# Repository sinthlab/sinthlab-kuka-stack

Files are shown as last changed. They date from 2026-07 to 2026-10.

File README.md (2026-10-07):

# Sinthlab KUKA Stack

A ROS 2 (Jazzy) control stack for running **compliant "apple‑pluck" experiments** on a KUKA
LBR iiwa7. It is built as an *overlay* on top of the [`lbr_fri_ros2_stack`][^1], adding the
high‑level experiment orchestration, motion actions, and the KUKA Sunrise (FRI) applications
needed to drive the arm.

All experiments run in FRI **position** mode, with the **cabinet** (`LbrImpedanceControlServer`)
providing the Cartesian spring at 1000 Hz. Apple-pluck / perturb stream **joint** setpoints via
`LBRJointPositionCommandController`; restricted-plane / maze stream a fixture-constrained **Cartesian
equilibrium** via `kuka_clik_controller`. Python state machines sequence each trial
(move → cue → monitor displacement → recoil → repeat).

The repo also carries the physical end of the rig: the parametric
[end‑effector design](end_effector_design/README.md) and the
[end‑effector board firmware](end_effector_metro_code/README.md) — a NeoPixel cue ring triggered
over a hardwired media‑flange line, whose **appearance is configured on the board over its own
Wi‑Fi**, see [§6.7](#67-end-effector-board--the-visual-cue).

**To run an experiment, start with the
[experiment control dashboard](#quick-start-the-experiment-dashboard)**, a local web page for
picking an experiment, editing its parameters, Start / Pause / Stop, changing cues between trials,
and following the status and log. Every experiment can also be run from a terminal
([§5](#5-running-experiments-on-hardware)).

Why FRI **position** mode rather than torque mode (ROS-side impedance), and when torque mode would be
worth reconsidering, is in the [appendix](#appendix--why-fri-position-mode-not-torque-mode).

## Table of Contents
- [Quick start: the experiment dashboard](#quick-start-the-experiment-dashboard)
- [1. Hardware Setup (KUKA Arm)](#1-hardware-setup-kuka-arm)
- [2. Windows Laptop Setup](#2-windows-laptop-setup)
- [3. Building the Stack](#3-building-the-stack)
- [4. Simulation & Visualization (no hardware)](#4-simulation--visualization-no-hardware)
- [5. Running Experiments on Hardware](#5-running-experiments-on-hardware)
  - [Pre-training — Free Move, Move Vertical, Move Horizontal](#pre-training--free-move-move-vertical-move-horizontal)
- [6. Software Architecture](#6-software-architecture)
- [7. Data Collected](#7-data-collected)
- [8. Troubleshooting](#8-troubleshooting)
- [9. Development & Contributing](#9-development--contributing)
- [Acknowledgement](#acknowledgement)
- [Appendix — why FRI position mode, not torque mode](#appendix--why-fri-position-mode-not-torque-mode)

---

## Quick start: the experiment dashboard

The quickest way to run an experiment is the **experiment control dashboard**, a local web page on
the ROS computer. From it you:

- pick one of the four experiments, or a pre-training task;
- check or change its parameters;
- Start, Pause, Stop and Restart it;
- change cues and other live settings between trials;
- follow the trial, its events and the full log.

Every experiment can still be run from a terminal instead: see
[§5](#5-running-experiments-on-hardware) and [Without the dashboard](#without-the-dashboard). How the
dashboard is built is in [`experiment_ctrl_gui/README.md`](experiment_ctrl_gui/README.md).

> ⚠️ **Stop is not an emergency stop.** It sends Ctrl-C to the launch. **The SmartPad E-stop is the
> E-stop.** On the first run of any experiment, work in **T1** with a hand on it.

### Start the dashboard
On the ROS computer wired to the arm, with the workspace built ([§3](#3-building-the-stack)):

```bash
~/lbr-stack/src/sinthlab-kuka-stack/experiment_ctrl_gui/run_gui.sh     # then open http://localhost:8080
```

Under WSL2 a Windows browser works, because Windows forwards `localhost` to WSL. `run_gui.sh`
sources ROS 2 and the workspace first. The page needs nothing extra installed and loads nothing
from the internet.

**Try it without the robot first.** This runs a simulated experiment with the same controls;
nothing is launched and nothing connects to the arm:

```bash
python3 ~/lbr-stack/src/sinthlab-kuka-stack/experiment_ctrl_gui/server.py --demo
```

| Option | Effect |
|---|---|
| `--port 8081` | serve on another port |
| `--robot-name lbr` | the arm's ROS namespace (default `lbr`) |
| `--demo` | simulated robot: nothing is launched |
| `--host 0.0.0.0` | serve beyond this computer. **Anyone who can reach the port can start the robot.** Prefer an SSH tunnel: `ssh -L 8080:localhost:8080 <ros-box>` |

### The page
- **Left column:** the experiment list (tabs **Experiments** and **Pre-training**), the **Run** controls, and a **Before you start** checklist
  with the SmartPad selections for the chosen experiment.
- **Middle column:** the **status**, then the **parameters**. Status shows the trial number, the
  current phase, the trial's steps, and a list of every event.
- **Log:** on the right on a wide screen, below on a narrow one.
- **Top bar pills:** the ROS connection, the robot (FRI session state and `lbr_state` rate), and the
  run state.

### Running an experiment
1. **Pick the experiment:** Apple Pluck, Apple Pluck Perturb, Restricted Plane or Maze; or, under
   **Pre-training**, Free Move, Move Vertical or Move Horizontal ([§5](#pre-training--free-move-move-vertical-move-horizontal)).
2. **Prepare the SmartPad.** Start `LbrImpedanceControlServer` and make the selections listed under
   *Before you start*: FRI send period, remote IP, stiffness profile, damping, elbow stiffness. **If the arm is nearly
   straight** (mechanical zero, or close to it), the app then asks to move it to the ready pose
   `[0, 10, 0, −80, 0, 90, 0]` — answer **Move to ready pose** and hold the enabling switch while it
   moves. The app then waits about 60 s for ROS.
3. **Check the parameters** ([below](#live-per-run-and-fixed-parameters)). Edited rows get an
   `edited` badge, and ↺ puts one back to the YAML value. Hover over any parameter for its full
   help.
4. **▶ Start.** This runs `ros2 launch sinthlab_bringup <experiment>.launch.py`, plus your edited
   parameters if you changed any. The status card then follows each trial, e.g.
   `start → at start → quiet → go cue → armed → threshold → recover → end`.
5. **Change live settings** on the **Live** tab at any time. A change applies **from the next
   trial**; the trial in progress is never changed. Until then the row shows a purple
   `next trial → …` badge, and the log records when the change was accepted and when it was applied.
6. **⏸ Pause after trial** lets the current trial finish. The arm recovers to the start and **holds
   there, still under control and compliant**. **▶ Resume** starts the next trial, with any live
   changes made meanwhile. Pressing the button again before the trial ends cancels the pause.
   **Free Move** has no trial end, so there the button (labelled **End session & pause**) ends the
   session at once: the arm holds, waits to be let go, returns to the start and holds.
7. **Stop:**
   - **■ Stop after trial:** finishes this trial, returns to the start, then stops cleanly, so every
     trial on disk is complete. **Use this one.** In **Free Move** (labelled **End session & stop**) it
     ends the session at once, waits for the hand to let go, returns to the start, then stops.
   - **■ Stop now:** Ctrl-C at once. The trial in progress is saved with `"partial": true`, and the
     arm stays where it is — it is not returned to the start.
   - **↻ Restart:** Stop now, then Start again with the current edits.
8. **Validate recording** checks this run's data folder
   (`analysis/validate_recording.py --folder …`) and prints the result in the log. To plot the
   run afterwards, see [Working with the data](#working-with-the-data).

**The log** is the launch's own output from every node, colour-coded by level. Filter it by level or
text, or turn off *Follow* to scroll back. It is also saved to `experiment_ctrl_gui/logs/`.

**An experiment started in a terminal** is picked up automatically. Live changes and pause work
from the page; stop it with Ctrl-C in its own terminal.

### Live, Per-run and Fixed parameters

| Tab | When it can change | What is in it |
|---|---|---|
| **Live** | Any time, **including while running**; applies from the next trial | cue switches, colours, tones and timing; NSP sync; move speeds; the pull threshold and hold; the perturbation; the start pose (apple pluck / perturb); the maze timeout ([full list](#live-parameters)) |
| **Per-run** | Before **Start**, then **locked for the run** | everything else in the experiment YAML: the start pose in restricted plane / maze, rails, checkpoints and goal, move tolerances, safety limits, the fixture profile, the displacement axis, frames, debug logging |
| **Fixed** | Not from the dashboard: at the SmartPad or in the file named | what every experiment shares: SmartPad (FRI) selections, launch arguments, `iiwa7_hardware_controllers.yaml`, the CLIK redundancy posture |

- **Your edits never change the package YAML.** They go into a copy for that run, and every
  recorded trial's sidecar keeps the full parameter set it ran with, live changes included.
- **Poses** are 7 joint angles in degrees. They are checked against the iiwa7 joint limits, and a
  nearly straight (singular) arm is refused — by the dashboard and again by the orchestrator.
  - **Start and recover are edited together**, because the next trial starts where the last one
    recovered to. A live change sends both in one call; one on its own is refused.
  - **Apple Pluck / Perturb:** the pose is live. The next trial moves to it and recovers to it.
  - **Restricted Plane and Maze:** the CLIK redundancy posture follows an edited start pose
    automatically.
  - **Maze:** a new start moves the whole maze with it. Run `check_maze.py` on the edited copy
    before trusting it.
- **Amber ⚠ notes** flag parameters other things depend on; **blue 🔗 notes** name what else an
  edit changes. Rails and checkpoints must keep their number of entries; adding a rail is a YAML
  edit.
- **Values are checked** for type, range and allowed choices before they are sent, and again inside
  the orchestrator. A refused change says why.

### Live parameters
**Every experiment:**

| Parameter | Meaning |
|---|---|
| `quiet_window_sec` | pause at the start pose before the go cue [s] (default 2.0) |
| `audio_cue.enabled` | master switch for every beep; off, the trial runs the same but silent |
| `audio_cue_*.frequency_hz`, `audio_cue_*.duration_ms` | each tone (37–32767 Hz, 10–10000 ms) |
| `visual_cue.enabled` | master switch for the NeoPixel ring |
| `visual_cue.remote_test_trigger` | fire the ring over its Wi-Fi (demos) or the X76 wire |
| `visual_cue.colours.<site>` | `[r, g, b, w]` per cue site (Wi-Fi trigger only) |
| `nsp_sync.enabled` | send event codes to the Blackrock NSP. **The DIO is not wired yet**: when on, it warns once and sends nothing ([§7](#sync-to-the-blackrock-nsp)) |
| `move_to_start.move_to_pos_v_max` / `_a_max` / `_j_max`, and the same for `move_to_start_recover` | move speed limits: peak joint speed 5–90 deg/s, acceleration 0.5–20 rad/s², jerk 1–150 rad/s³. The next move uses them. |

**Plus, per experiment** (`…displacement` = `apple_pluck_impedance_control_displacement`):

| Experiment | Extra live parameters |
|---|---|
| Apple Pluck | `…displacement.cartesian_displacement_threshold_m`, `…displacement.force_release_shutdown_delay_sec`, **the start / recover pose** (`move_to_start.target_joint_position`, `move_to_start_recover.target_joint_position`, set together) |
| Apple Pluck Perturb | everything Apple Pluck has, plus `…displacement.baseline_settle_sec`, `perturb_start.polar_r_m` (capped per plane), `perturb_start.polar_theta_deg`, `perturb_start.polar_plane`, `perturb_start.start_delay_sec`, and the perturbation's speed limits `perturb_start.move_to_pos_v_max` / `_a_max` / `_j_max` |
| Restricted Plane | `…displacement.cartesian_displacement_threshold_m`, `…displacement.force_release_shutdown_delay_sec` |
| Maze | `timeout_sec`, `virtual_fixtures.rail_lead_sec` (how easy moving along a rail feels: + lighter, − heavier, −0.15 to +0.05 s) |
| Free Move | `session_sec` (0 = until Pause / Stop after trial); the ring `ring_cue.quarters`, `ring_cue.colours.*`; the feel `free_move.damping_ns_per_m` (3–200, lower = lighter), `free_move.deadband_n` (0–15), `free_move.max_speed_mps` (≤ 0.5), `free_move.accel_limit_mps2`, `free_move.force_filter_tau_sec`, `free_move.tare_sec` |
| Move Vertical / Move Horizontal | `timeout_sec`, `virtual_fixtures.rail_lead_sec`, the task `travel_task.threshold_m` / `direction` / `require_return` / `return_tolerance_m`, the ring `ring_cue.quarters`, `ring_cue.colours.*` |

These are deliberately **not** live:
- `cartesian_axis`: it changes what the threshold means, so it is a different experiment, not a
  different trial.
- **Safety limits:** a limit must not be loosened mid-session.
- **Move tolerances** (`joint_move_tolerance`, `cartesian_move_tolerance`): they decide when a move
  counts as arrived.
- **The start pose in Restricted Plane and Maze:** those experiments hand the arm to the CLIK, whose
  redundancy posture must equal the start pose and is read once, when the controller starts; and the
  maze's geometry hangs off the start. Edit it per-run (the posture then follows automatically).
- **Maze rails, checkpoints and goal:** verified offline by `check_maze.py`.
- **The pre-training rails:** checked by IK for reach; edit them per-run.

### Parameter help
Each parameter shows a one-line description. **Hover over its name**, or tab to it, for the full
help:
- the type, YAML default, and allowed range or choices;
- whether it is live;
- the **notes from the YAML**: the reasoning, measurements and knobs;
- any caution or linked parameters.

Group headings and Fixed rows have the same help. To send someone straight to one parameter's help:
`http://localhost:8080/?exp=perturb&hover=perturb_start.polar_theta_deg`.

All of it is read from the YAML files themselves, so the page and the files cannot disagree. To
document a new parameter, see [§9](#9-development--contributing).

### Without the dashboard
The same controls from a terminal (namespace `lbr`, apple pluck shown). The orchestrator nodes are
`apple_pluck_orchestrator`, `perturb_orchestrator`, `restricted_plane_orchestrator` and
`maze_orchestrator`; for pre-training, `free_move_orchestrator` and `rail_training_orchestrator`
(Move Vertical and Move Horizontal).

```bash
ros2 launch sinthlab_bringup iiwa7_apple_pluck_impedance_control.launch.py                 # start; Ctrl-C stops
ros2 launch sinthlab_bringup iiwa7_apple_pluck_impedance_control.launch.py params_file:=/path/edited.yaml

ros2 topic echo /lbr/experiment_status                                                     # where the run is
ros2 param set /lbr/apple_pluck_orchestrator visual_cue.enabled false                       # live: next trial
ros2 param set /lbr/apple_pluck_orchestrator move_to_start.move_to_pos_a_max 1.0             # slower approach
ros2 service call /lbr/apple_pluck_orchestrator/pause std_srvs/srv/SetBool "{data: true}"   # pause after trial
ros2 service call /lbr/apple_pluck_orchestrator/pause std_srvs/srv/SetBool "{data: false}"  # resume
```

A `ros2 param set` on anything that is not live is **rejected with the reason**, because the
orchestrator read it once at start-up. The start and recover poses must change together, so set them
in one atomic call, `ros2 service call /lbr/apple_pluck_orchestrator/set_parameters_atomically …`, or
from the dashboard; `ros2 param set` on one of them alone is refused. The maze, restricted-plane and
pre-training launches also accept `clik_nullspace_cfg:=`.

### Files the dashboard writes
| Where | What |
|---|---|
| `experiment_ctrl_gui/runs/<exp>_<time>.yaml` | the edited parameter copy a Start used (only when something was edited), plus `…_clik_nullspace.yaml` when a CLIK start pose was edited |
| `experiment_ctrl_gui/logs/<exp>_<time>.log` | the full launch output of each run |
| `analysis/expt_<run_name>_<time>/` | the trial recordings, written by the orchestrator as always ([§7](#7-data-collected)) |

None of these are committed to git.

### If something is wrong
- **"ROS ✗" in the top bar.** The dashboard was started without ROS sourced, so use `run_gui.sh`.
  Start, Stop and the log still work, but live changes, pause and robot state need ROS.
- **"Robot: no state".** Nothing is publishing `/lbr/lbr_state` yet: the launch has not connected
  to FRI, or the SmartPad app is not running or timed out. Restart the app, then Start.
- **The run pill stays on "Starting…".** The orchestrator has not reported yet. Look in the log for
  its first lines or an exception.
- **A live change is refused.** The message gives the reason: not a live parameter, out of range, or
  wrong type. A per-run parameter needs Stop, edit, Start.
- **Stop takes a while.** The nodes shut down in order. After 20 s the dashboard escalates, and the
  log says so.
- **"Dashboard disconnected".** The dashboard server stopped. Restart it. If it was running an
  experiment, that experiment was stopped cleanly when the server stopped.

---

## 1. Hardware Setup (KUKA Arm)
- Use the "Quick Start guide" to cable up the Arm, Cabinet and the SmartPad.
- For the Safety on the X11 interface in the Cabinet:
  - First create 6 jumper cables with the provided pins.
  - Based on the PIN diagram (pg‑53 of `Spez_KUKA_Sunrise_Cabinet_en.pdf`, section 6.6.2),
    jump pins 1/2, 10/11 (external E‑Stop), 3/4, 12/13 (Operator Safety) and 5/6, 14/15
    (Safety stop 1).

---

## 2. Windows Laptop Setup
> **Why Windows + WSL2?** KUKA's robot software (Sunrise Workbench) requires Windows, while our
> stack requires Ubuntu. We use the Windows laptop to install applications onto the robot, and
> run our stack inside WSL2 (Ubuntu) on the same laptop to control the arm.

### Prerequisites
- Install Ubuntu 24.04 with `wsl --install -d Ubuntu-24.04` (the version matters — do **not**
  install the default).
- Confirm you are on WSL version 2 (`wsl -l -v` shows the version and the installed distro).
- Make sure the robot controller box is on.
- Install `Sunrise Workbench` on the laptop. For our arm version we use
  `SunriseWorkbench-1.17.0.4-setup.exe`, provided by KUKA Support.
- Install the FRI plugin in the Sunrise Workbench project (steps to be elaborated).

### Connection Verification
- Connect your computer to the robot controller at **X66** (default IP `172.31.1.147`) via an
  ethernet cable.
- Put your computer on the same network — set your IP to `172.31.1.148` (or anything else in the
  `/16` subnet).
  - On Windows: Settings → Network & Internet → Ethernet, edit the IPv4 manual setup to IP
    `172.31.1.148` and gateway `255.255.0.0`; leave other options as is and save.
- Ping the robot from PowerShell — `ping 172.31.1.147` — and expect something like:
  ```
  PING 172.31.1.147 (172.31.1.147) 56(84) bytes of data.
  64 bytes from 172.31.1.147: icmp_seq=1 ttl=64 time=0.868 ms
  ```
- Enable Hyper‑V on the laptop.
- Set up networking for WSL2: open WSL settings (in the Start menu) and change the Networking
  mode to **Mirrored**.
  
- In a PowerShell window **with admin privileges**, allow inbound Hyper‑V connections:
  ```powershell
  Set-NetFirewallHyperVVMSetting -Name '{40E0AC32-46A5-438A-A0B2-2B479E8F2E90}' -DefaultInboundAction Allow
  ```

### Install Application to Robot
Follow [these steps](https://lbr-stack.readthedocs.io/en/latest/lbr_fri_ros2_stack/lbr_fri_ros2_stack/doc/hardware_setup.html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)
to install the application to the robot. Our application is
[`sunrise_controller_code/LbrImpedanceControlServer.java`](sunrise_controller_code/LbrImpedanceControlServer.java);
redeploy it from Sunrise Workbench whenever that file changes.

### Tool Load Data (payload calibration)
The cabinet must know the end‑effector's mass, or the compliant control modes (Cartesian / joint
impedance) refuse to activate. With an uncalibrated tool the experiment launch aborts with:
```
[lbr_fri_ros2::StateGuard]: External torque not in limits for joint lbr_A2. Measured: 2.4 Nm, limit: 2 Nm
... External torque limits exceeded. Perform load data calibration!
```
You define a **tool** in Sunrise Workbench, then let the controller measure its mass and centre of
mass with the smartPAD's **Load data** view (Sunrise.OS 1.16 SI manual §7.5; ours is 1.17).

1. **Define the tool** in Sunrise Workbench — open the project's `RoboticsAPI.data.xml` and add a
   tool under `objectTemplates`. Keep the TCP at the flange (all‑zero transform) so the FRI control
   point stays aligned with the ROS `lbr_link_ee`, and leave `loadData` at zero (Determine fills it):
   ```xml
   <objectTemplates>
     <toolTemplate class="" defaultMotionFrameRef="/SinthLabIiwa7EE_link_ee" name="SinthLabIiwa7EE">
       <frames>
         <frame name="SinthLabIiwa7EE_link_ee">
           <transformation a="0.0" b="0.0" c="0.0" x="0.0" y="0.0" z="0.0"/>
         </frame>
       </frames>
       <loadData cogA="0.0" cogB="0.0" cogC="0.0" cogX="0.0" cogY="0.0" cogZ="0.0"
                 inertiaX="0.0" inertiaY="0.0" inertiaZ="0.0" mass="0.0"/>
     </toolTemplate>
   </objectTemplates>
   ```
   `defaultMotionFrameRef` must match the frame name exactly. **Synchronize** the project to the controller.
2. **Determine the load** on the smartPAD, in **T1**: at the **Robot** level select the **Load data**
   tile → pick `SinthLabIiwa7EE` → hold the enabling switch → **Determining the load data** →
   **Apply**. Then **synchronize** the project so Sunrise Workbench keeps the values.
   - Only the wrist moves: A7 goes to 0° then to −90°, and A6 swings ±95° (A1–A4 stay put). Tick
     **Restricted motion range for axis 6** (±15° around the start) if the effector could hit the arm.
   - Start from a pose well away from singularities, and make sure nothing on the tool can move: tie
     down cables and any battery pack. Loose parts, or anyone touching the robot, falsify the result.
   - **Below 1 kg KUKA calls the mass measurement unreliable.** Weigh the effector, enter the mass in
     the tool's `loadData`, synchronize, then choose **Use existing mass** so only the centre of mass
     is measured.
3. **Attach the tool in the FRI app** so the cabinet actually compensates it: in
   `sunrise_controller_code/LbrImpedanceControlServer.java`, create the tool
   (`createFromTemplate("SinthLabIiwa7EE")`), `attachTo(lbr_.getFlange())`, and move the **tool**
   instead of the bare flange. Without this the guard still trips even after Determine.

> **Apply** stores the mass / COM on the controller; synchronizing copies them back into the project's
> `RoboticsAPI.data.xml`. Re‑run after any change to the end‑effector — a different apple height or a
> moved battery pack counts. The `gravitation` vector in `RoboticsAPI.data.xml` assumes a standard floor mount;
> set it to match if the arm is mounted otherwise.

---

## 3. Building the Stack
> These steps run inside **WSL2 / Ubuntu 24.04**.

1. Install ROS 2 development tools (see this [guide](https://docs.ros.org/en/jazzy/Installation/Ubuntu-Install-Debs.html) for details):
   ```bash
   sudo apt update && sudo apt install locales
   sudo locale-gen en_US en_US.UTF-8
   sudo update-locale LC_ALL=en_US.UTF-8 LANG=en_US.UTF-8
   export LANG=en_US.UTF-8
   sudo apt install software-properties-common
   sudo add-apt-repository universe
   sudo apt update && sudo apt install curl -y
   export ROS_APT_SOURCE_VERSION=$(curl -s https://api.github.com/repos/ros-infrastructure/ros-apt-source/releases/latest | grep -F "tag_name" | awk -F'"' '{print $4}')
   curl -L -o /tmp/ros2-apt-source.deb "https://github.com/ros-infrastructure/ros-apt-source/releases/download/${ROS_APT_SOURCE_VERSION}/ros2-apt-source_${ROS_APT_SOURCE_VERSION}.$(. /etc/os-release && echo ${UBUNTU_CODENAME:-${VERSION_CODENAME}})_all.deb"
   sudo dpkg -i /tmp/ros2-apt-source.deb
   sudo apt update && sudo apt install ros-dev-tools
   sudo apt update
   sudo apt upgrade
   sudo apt install ros-jazzy-desktop
   sudo apt install python3-pip
   ```
2. Create a workspace, clone, and install dependencies:
   ```bash
   source /opt/ros/jazzy/setup.bash
   mkdir -p lbr-stack/src && cd lbr-stack
   vcs import src --input https://raw.githubusercontent.com/sinthlab/sinthlab-kuka-stack/main/sinthlab_lbr_stack.repos
   rosdep install --from-paths src -i -r -y
   ```
3. **(Hardware only, one-time)** Raise the FRI external-torque limit. `lbr_fri_ros2` checks the
   *external joint torque at activation of compliant control modes*. On a
   floor-mounted iiwa7 this trips (~2.4 Nm on A2 vs. the 2 Nm default) at the extended apple-pluck
   start posture **even with no payload** — it's a gravity-model / mastering margin amplified by A2's
   moment, not a real load. Edit the upstream config
   `src/lbr_fri_ros2_stack/lbr_description/ros2_control/lbr_system_config.yaml` and raise the limit
   (keep the check enabled):
   ```yaml
   state_guard:
     external_torque_safety_check: true
     external_torque_limit: 4.0   # upstream default is 2.0
   ```
   Skip this for mock/sim. The proper long-term fix is calibrating the mounted tool's load data (see
   §2 “Tool Load Data”) so the residual stays under the default — raising the limit is the stopgap
   while the flange is load-free.
4. Install the required Python packages (only needed once per WSL session install):
   ```bash
   pip install pyoptas ruckig --break-system-packages
   ```
5. Build:
   ```bash
   colcon build --symlink-install
   ```

---

## 4. Simulation & Visualization (no hardware)

The experiments themselves need the real arm: the cabinet provides the impedance spring and the
force estimate, which no simulation here reproduces. To try the trial flow and the dashboard without
it, run the dashboard in demo mode ([Quick start](#quick-start-the-experiment-dashboard)). To look at
the arm itself:

**Mock arm in RViz** (upstream `lbr_bringup`)
```bash
# Terminal 1 — the mock arm
source install/setup.bash
ros2 launch lbr_bringup mock.launch.py model:=iiwa7
```
```bash
# Terminal 2 — visualize
source install/setup.bash
ros2 launch lbr_bringup rviz.launch.py \
  rviz_cfg_pkg:=lbr_bringup \
  rviz_cfg:=config/mock.rviz
```

**Physics simulation in Gazebo** (upstream `lbr_bringup`)
```bash
source install/setup.bash
ros2 launch lbr_bringup gazebo.launch.py model:=iiwa7
```

**MoveIt with apple (mock or gazebo)**
```bash
source install/setup.bash

# Mock + MoveIt + RViz
ros2 launch sinthlab_bringup iiwa7_moveit_apple.launch.py mode:=mock rviz:=true

# Gazebo + MoveIt + RViz
ros2 launch sinthlab_bringup iiwa7_moveit_apple.launch.py mode:=gazebo rviz:=true
```

---

## 5. Running Experiments on Hardware
> Python dependencies (`pyoptas`, `ruckig`) must be installed once per WSL session install (see
> [Building the Stack](#3-building-the-stack)).
>
> ⚠️ **Safety first.** On the first run of any scenario, operate in **T1** (reduced speed) with a
> hand on the E‑stop. The arm is actively controlled the moment a SmartPad application is running.
>
> **Starting from mechanical zero.** A straight arm is singular, and impedance control cannot move it
> reliably. If `LbrImpedanceControlServer` starts with the arm nearly straight, it asks to move it to the
> ready pose `[0, 10, 0, −80, 0, 90, 0]` in position control first; answer **Move to ready pose**. From
> there every experiment's start is reachable. An arm already bent (e.g. at a start pose) is not moved.

### Running from the dashboard
The [dashboard](#quick-start-the-experiment-dashboard) runs exactly the launches below, with the
SmartPad checklist, parameters, status and log on one page. The steps below are the terminal way, and
what the dashboard does for you. The launches accept `params_file:=/path/to.yaml` to run an edited
parameter copy; the maze, restricted-plane and pre-training launches also accept `clik_nullspace_cfg:=`.

### Scenario quick reference
| # | Scenario | Launch file | SmartPad app (FRI) | ROS controller |
|---|---|---|---|---|
| 1 | Apple Pluck | `iiwa7_apple_pluck_impedance_control.launch.py` | `LbrImpedanceControlServer` | `LBRJointPositionCommandController` |
| 2 | Restricted on Plane  | `iiwa7_move_restricted_plane.launch.py` | `LbrImpedanceControlServer` | `kuka_clik_controller` |
| 3 | Apple Pluck Perturb  | `iiwa7_apple_pluck_impedance_perturb.launch.py` | `LbrImpedanceControlServer` | `LBRJointPositionCommandController` |
| 4 | Maze | `iiwa7_maze.launch.py` | `LbrImpedanceControlServer` | `kuka_clik_controller` |
| P | Pre-training (Free Move, Move Vertical, Move Horizontal) | `iiwa7_pretrain_<task>.launch.py` | `LbrImpedanceControlServer` | `kuka_clik_controller` |

**One control paradigm.** Every scenario uses FRI **POSITION** command mode with the **cabinet**
(`LbrImpedanceControlServer`) running the Cartesian impedance spring at 1000 Hz. They differ only in
what ROS streams into it:

- **Apple Pluck / Perturb (1 & 3)** — **joint** setpoints via `LBRJointPositionCommandController`
  (straight to the FRI position command, no IK).
- **Restricted-plane / Maze (2 & 4)** — a fixture-constrained **Cartesian equilibrium** via
  `kuka_clik_controller` (Cartesian target → IK → joint positions).

> **The two things that decide how a fixture feels:**
>
> 1. **Soft-inside comes from tracking, not from low stiffness.** Inside the allowed region the
>    fixture's projection returns the *measured* pose, so the spring error — and hence the force — is
>    ~zero **whatever K is**. High K only bites at the walls and on locked axes. What breaks this is
>    **tracking lag**: if the commanded equilibrium cannot keep up with the operator's hand it falls
>    behind *cumulatively* and `K × error` is felt as resistance in every direction. That is governed
>    by `kuka_clik_controller.max_linear_velocity` (**1.0 m/s**, well above hand-guiding speed) and
>    the fixture's `max_target_step_m` (**0.05 m**).
> 2. **Use an anisotropic stiffness profile.** `LbrImpedanceControlServer` takes a full per-axis
>    `{X,Y,Z,A,B,C}` diagonal. A *uniform* profile forces one compromise for locked axes, walls and
>    free motion alike, and for the maze no uniform value works (400 = mushy walls, 3000 = heavy
>    everywhere). Lock the constrained axis hard and keep the free axes firm enough for
>    walls; the interior stays free by (1).

### Scenario 1 — Apple Pluck
This scenario streams **joint** setpoints to the `LBRJointPositionCommandController` (joint positions
go straight to the FRI position command — no IK), while the KUKA cabinet runs Cartesian impedance
natively via the `LbrImpedanceControlServer` FRI app. The arm acts as a virtual physical spring and
recoils when pushed off its commanded anchor.

**Start pose — the apple points at the monkey.** The effector is tilted **25° below horizontal** toward
the monkey (+X), so the monkey pulls the apple toward itself and the NeoPixel ring faces it. Flange
≈ (0.40, 0, 0.75) m, apple ≈ (0.56, 0, 0.68) m in `lbr_link_0`, reached with the in-plane posture
`[0, −15.5, 0, −94.3, 0, 36.2, 0]`. It was solved by IK against the iiwa7 URDF, and the arm can be
pulled at least 0.30 m toward the monkey before nearing a joint limit or singularity. A **pluck** is any
**0.1 m** pull from the start, in any direction (`cartesian_axis: norm`), because the pull is toward
the monkey rather than along one base axis. Tilt, roll and height knobs are documented next to the
pose in `config/apple_pluck_impedance.yaml`.

**Steps to run:**
1. On the KUKA SmartPad, start the **`LbrImpedanceControlServer`** application. It opens five
   selection dialogs in sequence — choose:

   | Prompt | Select |
   |--------|--------|
   | FRI send period [ms] | `10` |
   | Remote IP address | `172.31.1.148` (your ROS / WSL2 laptop IP) |
   | Cartesian stiffness (K diagonal) | `Uniform Medium (Apple Pluck)` |
   | Damping ratio (D0) | `0.7 (Standard)` |
   | Null-space (elbow) stiffness | `30 (Standard)` |

   *This app is hard‑wired to Cartesian Impedance control in `POSITION` command mode. The other
   stiffness profiles (`Very Soft Z`, `Soft Z (Apple Pluck)`, `Stiff (firm walls)`, …), damping ratios
   (`0.1`, `0.2`, `0.3`, `1.0`) and elbow stiffnesses (`15`, `5`) are available if you want to change
   the feel.*
   The app then waits (~60 s) for the ROS client to connect.
2. **Launch the experiment** — this connects ROS to the waiting FRI app and starts the trial loop
   (nothing happens until you run this):
   ```bash
   ros2 launch sinthlab_bringup iiwa7_apple_pluck_impedance_control.launch.py
   ```
3. The arm moves to the start. At the beep (and a **green** ring, if the visual cue is on) pull the
   apple toward you; **0.1 m** in any direction counts. A second beep and a **red** ring confirm it,
   the arm holds for a moment, then returns to the start.

### Scenario 2 — Move Restricted on a Plane
This scenario applies mathematical **virtual fixtures** (planes, boxes, cylinders, sine rails): the
arm moves freely *within* an allowed region and is pushed back *outside* it. `kuka_clik_controller`
streams a **fixture-constrained equilibrium** pose (the measured pose projected onto the allowed
manifold) and the cabinet's Cartesian impedance turns that into the free-motion + wall feel at 1000 Hz.
Along a free axis the equilibrium tracks the arm, so the spring error — and the force — is ~zero; off
the manifold it stays put, so the spring pulls the arm back.

**Steps to run:**
1. On the KUKA SmartPad, start the **`LbrImpedanceControlServer`** application. It opens five dialogs:

   | Prompt | Select |
   |--------|--------|
   | FRI send period [ms] | `10` |
   | Remote IP address | `172.31.1.148` (your ROS / WSL2 laptop IP) |
   | Cartesian stiffness (K diagonal) | **`Rail guide (uniform 1000)`** |
   | Damping ratio (D0) | `0.7 (Standard)` |
   | Null-space (elbow) stiffness | `30 (Standard)` |

   The app then waits (~60 s) for the ROS client to connect.
2. **Launch the experiment** — this connects ROS to the waiting FRI app and starts it:
   ```bash
   ros2 launch sinthlab_bringup iiwa7_move_restricted_plane.launch.py
   ```
3. The arm rises to the workspace; pull it and feel it held onto the sine rail — free along the pull
   axis, walled in the other two.

> **Tune the feel with the SmartPad stiffness profile.** `Rail guide (uniform 1000)` pins X and holds
> the arm to the rail in Y, while Z (the pull axis) stays free because the equilibrium tracks it. If
> the pull feels heavy *while moving* rather than at the rail, that is tracking lag, not stiffness —
> raise `kuka_clik_controller.max_linear_velocity`.
>
> **Tip:** Set `virtual_fixture_profile` (`sine_wave`, `flat_table`, …) in
> `virtual_fixtures_params.yaml` — this defines *where* the fixture is. For the sine rail, size the
> **wavelength against the pull stroke** — below ~1 period over the stroke it reads as a straight lean.

#### How this relates to Apple Pluck — same cabinet compliance, different ROS controller
Both run the **same cabinet Cartesian impedance at 1000 Hz**; they differ in what ROS streams:

| | Apple Pluck (1 & 3) | Restricted Plane / Maze (2 & 4) |
|---|---|---|
| SmartPad app | `LbrImpedanceControlServer` | `LbrImpedanceControlServer` |
| Compliance | **cabinet** Cartesian impedance, 1000 Hz | **cabinet** Cartesian impedance, 1000 Hz |
| ROS controller | `LBRJointPositionCommandController` | `kuka_clik_controller` |
| ROS streams | **joint** positions (the start config) | a **Cartesian** pose projected onto the fixture manifold |
| Stiffness profile | uniform (omnidirectional spring) | **anisotropic** (lock one axis, firm walls on the others) |
| Feel | omnidirectional spring toward one pose | free within the fixture; firm wall outside it |

So the cabinet — not Python — supplies the give: the arm yields to a sudden jerk at 1 kHz, and the
"walls" are **soft impedance walls** (the arm is gently pulled back onto the manifold), which is the
safer behaviour for an animal subject. The software (`MoveRestrictedOnAPlaneAction`) just keeps the
spring's equilibrium inside the allowed region.

### Scenario 3 — Apple Pluck Perturb
This scenario builds upon the Apple Pluck physics (cabinet‑side Cartesian impedance via
`LbrImpedanceControlServer`, with `LBRJointPositionCommandController` streaming the joint setpoints) but
introduces a sudden, programmatic Cartesian spatial shift right before the user acts, to study the
response to mechanical perturbation.

It uses the **same start pose** as Apple Pluck (apple pointing at the monkey). The pluck threshold is
**0.1 m** in any direction (the same as Apple Pluck), measured from where the arm settles after the
perturbation.

**Tuning the perturbation** — `perturb_start` in `config/apple_pluck_impedance_perturb.yaml`:

| Knob | Effect |
|---|---|
| `polar_r_m` | How far the apple is displaced [m]. Default `0.05`. **Capped per plane:** frontal 0.15, horizontal 0.175, sagittal 0.10 m, so every direction stays ≥ 10° from every joint limit. Larger r also tilts the flange more (up to ~22° at the frontal cap). |
| `polar_plane` | `frontal` (default) — the plane **facing the monkey**, so the apple never moves toward or away from it. `horizontal` / `sagittal` — θ = 0 points **at** the monkey. |
| `polar_theta_deg` | Direction in that plane. For `frontal`: `0` = +Y (sideways), `90` = up, `180` = −Y, `270` = down. |
| `move_to_pos_a_max`, `move_to_pos_j_max` | **How fast.** On a short move the acceleration and jerk limits set the duration. |
| `move_to_pos_v_max` | Per-joint speed cap. It never binds on a 5–10 cm perturbation. |
| `start_delay_sec` | Wait after the start cue before the perturbation begins [s]. Default `1.5`. |

Measured from the start pose at r = 0.05 m (motion of the impedance anchor):

| `a_max` / `j_max` | Duration | Peak apple speed |
|---|---|---|
| 2 / 5 *(default)* | 0.73 s | 0.13 m/s |
| 5 / 20 | 0.46 s | 0.20 m/s |
| 10 / 50 | 0.34 s | 0.28 m/s |
| 20 / 150 | 0.23 s | 0.40 m/s |

The physical apple follows the anchor through the impedance spring, so it lags a very fast perturbation.

**Steps to run:**
1. On the KUKA SmartPad, start the **`LbrImpedanceControlServer`** application with the **same
   selections as Scenario 1**:

   | Prompt | Select |
   |--------|--------|
   | FRI send period [ms] | `10` |
   | Remote IP address | `172.31.1.148` (your ROS / WSL2 laptop IP) |
   | Cartesian stiffness (K diagonal) | `Uniform Medium (Apple Pluck)` |
   | Damping ratio (D0) | `0.7 (Standard)` |
   | Null-space (elbow) stiffness | `30 (Standard)` |

   The app then waits (~60 s) for the ROS client to connect.
2. **Launch the experiment** — this connects ROS to the waiting FRI app and starts it:
   ```bash
   ros2 launch sinthlab_bringup iiwa7_apple_pluck_impedance_perturb.launch.py
   ```
3. The arm acts as the standard pluck, but **1.5 s after the start cue** (`start_delay_sec`) it moves
   the apple **5 cm sideways** in the plane facing the monkey. Pull from where it settles: **0.1 m** in
   any direction counts.

### Scenario 4 — Maze
The operator (or animal) drives the compliant arm along a network of **linear rails** in a **vertical
Y‑Z plane** in front of the robot. It reuses the same fixture engine as Scenario 2
(`MoveRestrictedOnAPlaneAction` with the `maze` profile). Hitting a checkpoint plays a reward cue
(**any order, once each**); reaching the goal — or timing out — stops the fixtures, waits for the
operator to let go, and resets to the start.

**The legs are LINES, not corridors.** Each "corridor" in `maze_params.yaml` is a *degenerate*
rectangle — a horizontal leg has `b_min == b_max`, a vertical leg has `a_min == a_max` — so the fixture
always projects the equilibrium onto the **nearest segment**, exactly like the sine rail. You slide
*along* a rail and can only turn at a junction; there is no free area to wander in.

**Why vertical, and why this start posture.** The tool axis (the EE frame's **Z** axis) points ~+X at
the subject, and the maze locks base‑X so the plane is enforced by the cabinet. The start posture
matters more than it looks: both fixtures **lock orientation**, and translating the EE while holding
orientation is far more expensive in some arm configurations than others. The start posture reaches
its EE pose with the **elbow flipped** relative to the obvious solution, which puts the cost of sideways
motion at ‖q̇‖ ≈ 2.5 instead of ≈ 19.8 (6D condition number 10 instead of 45). In the other posture the
maze is heavy in exactly the directions it is supposed to be free.

**Workspace limits (measured by IK, holding tool orientation).** From the shipped start the arm can
reach **a ∈ [−0.40, +0.40] m** sideways and **b ∈ [−0.35, +0.20] m** up/down — but that envelope is a
**trapezoid**: full width low down, pinched at the top (at b = +0.20 only a ∈ ±0.10).

**Why the maze sits entirely at or below the start.** Climbing is hard on this arm for two independent
reasons, both measured:

| | sideways cost | vertical cost | gravity at the tool |
|---|---|---|---|
| low (b = −0.15) | 2.8 | **3.4** | −5.3 N |
| high (b = +0.15) | 3.4 | **8.6** | −5.4 N |

1. The gravity-compensation residual is a constant **~5.5 N downward**, so climbing fights it and
   descending is assisted.
2. **Vertical conditioning degrades with height** — the cost of vertical motion with orientation held
   is 3.4 low down but **8.6** near the top, 2.5× the sideways cost there.

So the maze's rows are at **b = 0, −0.11 and −0.22**: every vertical leg is in the well-conditioned
lower region and gravity is on the operator's side. The depth stops at −0.22 so the goal row stays at
a comfortable height (z ≈ 0.64 m in the base frame).

**The maze is defined RELATIVE to the start EE** (`corridor_frame: relative`, `relative_to_start: true`),
so its origin is wherever the arm starts: change `move_to_start` and the whole maze — rails, checkpoints,
goal — moves with it. It is anchored on the **settled measured** pose, not the commanded one
(`anchor_settle_sec: 3.0`, `anchor_on_measured: true`): a free axis carries no restoring force, so the
arm sinks a few cm below the commanded start; anchored on the command, the whole maze would sit that
far overhead and the checkpoints would be missed.

#### What you should expect to see

A **2-D maze** of linear rails on a 0.15 m grid — shaded cells are solid, you can only travel the
rails, and only one route reaches the goal. Coordinates are **offsets from the anchored start**
(▶ = 0,0): **a = Y sideways, b = Z up/down**; X (in/out) is locked by the cabinet.

```
   a:      -0.30     -0.15      0.00     +0.15
         ┌────────────────────────────┐
 b  0.00 │░░░░░░░░░░░░░░░░░░▶════════┐│  ▶ START
         │░░░░░░░░░░░░░░░░░░░░░░░░░░░║│
 b -0.11 │┌════════◆═════════════════┘│  ◆ fork (reward cue)
         │║░░░░░░░░║░░░░░░░░░░░░░░░░░░│
 b -0.22 │└════════◆═════════════════★│  ★ GOAL — below the start
         └────────────────────────────┘
            the two ◆ are the only choices; every vertical leg is DESCENDED
            ░ = solid (no rail)     ═ ║ ┌ ┐ └ ┘ = rail you can travel
```

**A checkpoint fires only where a turn decision is actually made** — the **two** junctions offering a
real choice (◆). Every other junction is a corner where the turn is forced, and arriving at one tells
the subject nothing to act on, so it gets no cue. A reward tone therefore means exactly one thing:
**"you are at a fork — choose."**

| fork | the choice |
|---|---|
| (−0.15, −0.11) | drop here for the **short** route, or carry on left and drop at a = −0.30 (**long**) |
| (−0.15, −0.22) | turn right for the goal, or left along the bottom (the long way round) |

The descent at a = −0.15 is a **single rail** from the first fork straight down to the second — nothing
branches off it in between, so its midpoint is not a junction and deliberately gets no cue.

**The choice is which column to descend.** Drop at a = −0.15 for the **short route (0.97 m)**, or carry
on to a = −0.30 and drop there for the **long route (1.27 m)**. Both reach the goal row, so there are
**no dead ends** — a wrong choice costs travel rather than trapping the arm. Every vertical leg is
descended, never climbed.

**The walls hold you.** The fixture latches onto the rail you are travelling and will only hand you
over to a rail that *physically touches* it — a real junction. Push sideways mid-rail and the
equilibrium stays clamped to that rail, so the cabinet spring pulls you back onto it. A hard push can
never make an unrelated rail "nearest" and drag the arm through a wall.

**The gap matters.** On the b=0 row there is deliberately **no rail between a=−0.15 and a=0.00**
(the shaded cells left of ▶). Without it the arm could run straight from START to the goal up-link and
the maze would be trivial — that gap is what forces the long way round.

Every rail is verified reachable by IK while holding the tool orientation (40 samples along the rails,
all reachable, sideways cost median 2.9 / max 3.5).

#### Changing or extending the maze

**The maze is pure configuration — you never edit code to change it.** Everything lives in
`sinthlab_bringup/config/maze_params.yaml`, and the geometry is *relative to the start*, so the whole
maze follows `move_to_start` automatically.

**Rails** are four parallel arrays under the `maze` profile — one entry per segment:

```yaml
#                R1     R2     R3   ...
corridor_a_min: [ 0.00,  0.15, -0.30, ...]   # a = Y sideways
corridor_a_max: [ 0.30,  0.15,  0.30, ...]
corridor_b_min: [ 0.00, -0.15, -0.15, ...]   # b = Z up/down
corridor_b_max: [ 0.00,  0.00, -0.15, ...]
```

A **horizontal** rail has `b_min == b_max`; a **vertical** rail has `a_min == a_max`. If both spans are
non-zero you have made a *box* — an open area the arm can wander inside — not a rail.

**Rules the maze must obey**

| rule | why |
|---|---|
| no key defined twice in the same block | YAML silently keeps the **last** one, so the file says one thing and ROS loads another |
| every rail linear (degenerate in one axis) | otherwise it is an open box, not a corridor |
| all four `corridor_*` arrays the same length | they are read positionally |
| START `(0,0)` lies on a rail | otherwise the arm begins pinned against a wall |
| segments **touch** to form junctions | rails that don't touch are separate; the arm can't cross between them |
| every checkpoint and the goal lies on a rail | a waypoint off the rails can never be triggered |
| `checkpoint_x/y/z/radius` the same length | read positionally, like the rails |
| `maze_safety.max_displacement_m` exceeds the farthest rail point | otherwise the safety stop fires mid-trial |
| fits the reachable envelope | see below |

**Reach.** Holding the tool orientation, the arm covers **a ∈ [−0.40, +0.40]**, **b ∈ [−0.35, +0.20]**,
and that envelope is a **trapezoid** — full width low down, sharply pinched at the top (at b = +0.20
only a ∈ ±0.10). Vertical room is the scarce resource; sideways room is plentiful.

**If you change `move_to_start`**, you must also update `config/clik_nullspace_maze.yaml`
(`nullspace_desired_configuration`) to the same joint array, or the CLIK will hold the right EE pose in
the wrong arm posture. And re-check the *orientation-constrained* cost of the free directions — that is
what decides whether guiding feels light or like treacle, and it is not visible in reach alone.

**Validate before you touch the robot:**

```bash
# reach checks need a generated URDF (once per shell)
xacro $(ros2 pkg prefix lbr_description)/share/lbr_description/urdf/iiwa7/iiwa7.xacro > /tmp/iiwa7.urdf
export IIWA7_URDF=/tmp/iiwa7.urdf

ros2 run sinthlab_bringup check_maze.py
```

It checks every rule above, then IKs points along each rail to confirm the arm can actually reach them
while holding the tool orientation, and reports the sideways-motion cost. Exit code is non-zero on
failure, so it works in CI. Example of a bad maze:

```
  [--] key 'checkpoint_x' is defined TWICE in the same block (second at line 156).
       YAML keeps the LAST one, so the file does not say what ROS loads.
  [--] rails [10] have width in BOTH axes -- they are boxes, not lines.
  [--] rails [10] are NOT connected to the start -- unreachable, the arm can never enter them.
  [--] CP4 is 70 mm off every rail -- it can never be triggered.
  [--] maze reaches 0.99 m but maze_safety.max_displacement_m is 0.20 -- the safety stop
       would fire mid-trial. Raise it above 0.99.
FAILED (5 problem(s))
```

The duplicate-key check runs **first**. A YAML file with the same key twice parses cleanly and the
later value silently wins, so every other check would pass while the maze loads different values than
the file appears to specify.

Structural checks run without the URDF; the kinematic ones are skipped with a note if `optas` or
`IIWA7_URDF` is unavailable.

**Making it harder.** Add rails (junctions, dead ends, loops), not width. Length is cheap along `a`,
expensive along `b`. A deliberate **gap** between two collinear rails — as between `a = −0.15` and
`a = 0.00` on the b = 0 row — is what forces the long way round; without gaps a grid of rails is just
an open field.

#### Diagnostic ladder

If the maze feels wrong, switch `virtual_fixture_profile` to isolate the cause — these need no code
change, because a rail spanning the whole workspace has no walls and a long thin one *is* a line:

| profile | what it is | what it tests |
|---|---|---|
| `free_plane` | one huge corridor, no reachable wall | the plane lock + stiffness + tracking, with the maze removed |
| `single_line` | one corridor, long in Y, ±2 cm in Z | adds exactly one wall pair |
| `maze` | the real thing | full geometry |

Work up the ladder and stop at the first rung that feels wrong.

**Steps to run:**
1. On the KUKA SmartPad, start the **`LbrImpedanceControlServer`** application:

   | Prompt | Select |
   |--------|--------|
   | FRI send period [ms] | `10` |
   | Remote IP address | `172.31.1.148` (your ROS / WSL2 laptop IP) |
   | Cartesian stiffness (K diagonal) | **`Maze walls + easy guiding (rot 120)`** — `{2500, 1000, 1000, 120, 120, 120}` |
   | Damping ratio (D0) | `0.7 (Standard)` |
   | Null-space (elbow) stiffness | `30 (Standard)` |

   > **Use an anisotropic profile, not a uniform one.** X 2500 locks the radial axis so the cabinet
   > enforces the plane in hardware; Y/Z 1000 holds the arm firmly on the rails. Uniform profiles could
   > never win: 400 made the walls mushy, 3000 made everything heavy.
   >
   > Four maze profiles ship, differing **only in rotational stiffness** — `Maze walls (X lock, Y/Z
   > firm)` 300, `… easy guiding` 120, `… light guiding` 60, `… very light guiding` 30 — so you can A/B
   > the one knob that matters for feel. The maze's constraints are all *translational* (X = the plane, Y/Z =
   > the rails), so orientation stiffness defines nothing about the maze — it only stops the tool
   > twisting. But holding orientation *while translating* is the expensive motion, so dropping it to
   > 120 (or 60, or 30) reduces guiding effort **without** softening the plane or the rails. Trade-off:
   > the tool twists more as rot drops — watch the apple angle.
2. **Launch:**
   ```bash
   ros2 launch sinthlab_bringup iiwa7_maze.launch.py
   ```
3. The arm drives to ▶START. (From a straight arm, the SmartPad app has already moved it to the
   ready pose, from which the maze start is reachable.)
4. The arm settles for 3 s, the fixture anchors on where it **rests**, the go cue plays, and the rails go
   live. Drive to the goal (or let the 60 s timeout expire).

   > **Watching progress.** The fixture logs your maze position at 2 Hz:
   > `maze: a=+0.180 b=+0.002 -> on rail C1`, or `OFF rail (nearest C1, 31 mm away, being pulled back)`.
   > Every run also writes `analysis/robot_trajectory_*.csv` with
   > `time, x, y, z, rel_a, rel_b, corridor, off_rail, rail_dist` — plot `rel_a` vs `rel_b` straight on
   > top of the rail coordinates in `maze_params.yaml`. Set `checkpoint_monitor.debug_log_enabled: true`
   > to also see live distance to each checkpoint and the goal.

> **⚠️ Gravity matters on the free axes.** Along a rail the equilibrium tracks the arm, so the spring
> exerts ~no restoring force in that direction and the tool's weight rests on **gravity compensation**.
> Measured on the bare flange: the arm sinks ~4 cm and then **stops** (bounded, not a runaway). That is
> why the fixture anchors on the settled pose. With the real EE mounted, run tool-load **Determine**
> first — a wrong `loadData` makes the sink larger and biases every vertical leg.
>
> **Safety-stop (backstop, not a substitute).** `SafetyStopMonitor` (`maze_safety` in the params) trips if
> the EE leaves the start pose by > 0.55 m or exceeds 0.7 m/s (for 5 consecutive samples), and **aborts immediately** —
> stops the fixture and drives back to the start posture, no release wait. This exists because the FRI
> velocity guard only *neutralises the command*, it does not halt the trial. It catches a runaway; it does
> not remove the need for correct gravity compensation.
>
> **Tuning the feel.** The goal is effortless movement *along* a rail and a hard wall *across* it.
> Along a rail the spring exerts no force by design (the equilibrium is the arm's own position
> projected onto the rail), so what you feel there comes from lag, damping and the orientation lock.
> The levers, in the order worth trying:
> 1. **`virtual_fixtures.rail_lead_sec`** — the **ease knob**, Live between trials. It aims the
>    equilibrium slightly *ahead* of the arm along the rail it is on, cancelling the tracking lag that
>    reads as drag (the equilibrium reaches the arm a few tens of ms late, and stiffness × speed × lag
>    pulls back). `0` = off; **+0.01 to +0.03** = lighter (at 0.2 m/s, +0.03 is ~6 N of assist);
>    the cap is +0.05, because beyond the real lag the arm starts to pull itself along; **negative** =
>    a deliberate speed-dependent drag, if the task should be harder. It never acts across a rail, so
>    the walls are unchanged, and never leads more than 2 cm.
> 2. **Damping ratio** (SmartPad: 0.1 / 0.2 / 0.3 / 0.7 / 1.0). The cabinet damps the arm's velocity,
>    which is felt as drag along the rail that grows with speed. Lower is lighter; check the walls and
>    the return to start do not ring.
> 3. **Rotational stiffness** (SmartPad maze profile: rot 300 / 120 / 60 / 30): the biggest lever on
>    how heavy guiding feels even when moving slowly, and it costs no fixture fidelity — only more tool
>    twist.
> 4. **Null-space (elbow) stiffness** (SmartPad: 30 / 15 / 5 Nm/rad): how firmly the elbow is held.
>    Moving the flange moves the elbow too, so this is felt as a steady resistance; lower is lighter,
>    but watch the elbow does not swing.
> 5. **Y/Z stiffness**: how firmly you are held on a rail. Raise if the rails feel mushy.
>
> **What is left when all of these are at their lightest** is the arm's own inertia and drive
> friction (about 23 kg of links to move), and the walls catching the part of your push that is not
> exactly along the rail. Separate the two with the ladder: profile **"Diagnostic: nearly free
> (uniform 50, rot 10)"** + `virtual_fixture_profile: free_plane` shows the floor — how light the arm
> can feel at all (diagnostic only; walls and plane lock are meaningless at that stiffness). Then the
> maze profile + `free_plane` adds the plane lock, `single_line` adds one wall pair, and `maze` adds
> the rails. Wherever it gets clearly heavier is the part to work on.
>
> Damping 0.1 / 0.2 apply to the Cartesian spring only; the elbow's damping stays at 0.3, Sunrise's
> minimum for it.
>
> To tell them apart, move along one rail at a steady speed and watch
> `ros2 topic echo /lbr/force_torque_broadcaster/wrench --field wrench.force` (it reads 0 below 2 N).
> Drag that grows with speed is lag or damping; a push-back that is there even when you move slowly
> is the orientation lock or gravity.
>
> If a *free* direction feels heavy no matter what, suspect the **start posture** rather than any of
> these — see the note on orientation-constrained translation above.

> **Moving the maze = changing `move_to_start`.** Because everything is start-relative, the joint start
> pose is the one knob that positions the maze. Everything moves with it automatically — but you still have
> to respect **reach**: holding the start orientation the arm covers **a ∈ [−0.40, +0.40], b ∈ [−0.35,
> +0.20]**, and that envelope is a trapezoid (pinched at the top). Every rail point in the shipped maze
> is verified reachable. If you pick a very different start, re-check the footprint **and** re-check the
> orientation-constrained cost of the free directions — a bad posture reintroduces the treacle feel.
>
> **Two syncs to keep (both are pre-set):**
> - `config/clik_nullspace_maze.yaml` `nullspace_desired_configuration` **must equal**
>   `move_to_start.target_joint_position`. The CLIK matches only the EE *pose* and resolves the arm's
>   redundant 7th DOF toward that posture; a mismatch holds the right pose in the wrong arm shape.
> - `checkpoint_monitor.relative_to_start` and the fixture's `corridor_frame` must **both** be relative (or
>   both absolute), or the rewards land in the wrong place relative to the walls.
>
> **Editing the shape:** rails live in `maze_params.yaml` as `corridor_a_min/a_max/b_min/b_max`
> (with `restricted_axis: x`, `a = Y` sideways and `b = Z` up/down, as **offsets from start**). Keep them
> degenerate — a horizontal leg has `b_min == b_max`, a vertical leg has `a_min == a_max` — or you get a
> box with free area inside it again. Segments must **touch** to form a junction; START (0,0) must lie on
> one; the checkpoint/goal **X**-offset is 0 (on the locked plane), and Y/Z carry the position.

### Pre-training — Free Move, Move Vertical, Move Horizontal
Three short tasks that get a subject used to the arm before the real experiments. In the dashboard
they are under the **Pre-training** tab. All three:

- start at the **maze start** (tool along +X toward the subject), so they share one posture with the
  maze;
- run on the CLIK, like the maze;
- end like the maze: a cue, then the arm holds and waits for the hand to let go, then it returns to
  the start.
- record the same per-trial CSV and sidecar, into `analysis/expt_iiwa7_pretrain_<task>_<time>/`.

| Task | Launch file | SmartPad stiffness | The subject… | Success |
|---|---|---|---|---|
| **Free Move** | `iiwa7_pretrain_free_move.launch.py` | **Rail guide (uniform 1000)** | moves the arm anywhere; it stays where it is let go | no goal — one session, until you end it (Pause / Stop after trial) |
| **Move Vertical** | `iiwa7_pretrain_move_vertical.launch.py` | **Maze walls + easy guiding (rot 120)** | slides it up or down one vertical rail to the threshold (0.10 m), then back | back at the start |
| **Move Horizontal** | `iiwa7_pretrain_move_horizontal.launch.py` | **Maze walls + easy guiding (rot 120)** | slides it left or right along one horizontal rail, then back | back at the start |

Use **damping 0.7** and **elbow 30** for all three. Move Vertical and Move Horizontal share one
orchestrator (`rail_training_orchestrator.py`); their YAML picks the rail. Free Move has its own
(`free_move_orchestrator.py`).

#### Free Move — admittance, no goal, no boundary
The arm goes wherever it is pushed and stays wherever it is let go. There is no goal, no reward and
no wall. It runs as one free-movement **session** until you end it with **Pause** or **■ Stop after
trial** on the dashboard: an end tone plays, the arm holds where it is, waits to be let go, and returns
to the start. There it holds (Pause; **▶ Resume** starts a new session) or the launch stops (Stop after
trial). **■ Stop now** does not return it: the arm stays where it is. For timed sessions instead, set
`session_sec` (live; 0, the default, means no limit).

ROS owns the cabinet spring's **equilibrium** and moves it at a speed proportional to the hand's force
(`speed = force / free_move.damping_ns_per_m`). The cabinet spring then pulls the arm after it
([`admittance_move.py`](sinthlab_bringup/sinthlab_bringup/actions/admittance_move.py)). The CLIK still
does the IK; ROS only moves the target point.

- **The feel is set in the YAML, not on the SmartPad, and all of it is live.**
  - `damping_ns_per_m`: the only resistance — lower is lighter. At 10, 3 N of push moves the arm
    about 0.3 m/s. Very low values may buzz or oscillate; come down gradually.
  - `deadband_n`: a **threshold**, not a subtraction. A force below it moves nothing; above it the
    whole force counts (full from twice the threshold). Raise it if the arm creeps when nobody touches
    it. The force estimator has its own 2 N per-axis dead band on top
    (`estimated_wrench_interface` in `config/iiwa7_hardware_controllers.yaml`).
  - `max_speed_mps`: speed cap, 0.35 m/s by default.
  - `accel_limit_mps2`: **smoothness** — how fast the speed may change (default 1.5 m/s²; 0 = off).
    The force estimate is noisy and flickers across the threshold; without this the speed follows
    every jolt and the motion feels bumpy. Lower is smoother, but slower to start and stop.
  - `force_filter_tau_sec`: low-pass on the force estimate (larger = smoother, but laggier, and lag
    can make low damping oscillate).
- **Where the force comes from** (`force_source`, per-run). By default (`joint_torques`) Free Move
  computes the hand's force itself from the arm's **external joint torques** through the Jacobian
  (`F = pinv(J)ᵀ τ_ext`, lightly damped: `jacobian_damping` 0.02). It does **not** use lbr's estimated
  wrench topic, for two reasons that made diagonal motion bumpy:
  - that estimator has a **per-axis** 2 N dead band, so a diagonal push, split across axes, switches
    on and off axis by axis and its direction snaps between them;
  - its Jacobian inverse is damped at 0.2, which here reads only **47–85 %** of the real force and
    bends its direction by up to **17°**, differently in different directions.

  In an offline test of a 6 N diagonal push, the estimator path barely moved (0.007 m/s, about 26°
  off the push); the joint-torque path moved at full speed within about 2° of it. `force_source:
  estimator` switches back. The estimator topic itself is unchanged, so the release check still uses
  it. Because the force is no longer under-read, the same damping feels **lighter** than with the
  estimator.
- **Why "Rail guide (uniform 1000)".** The spring is what makes the arm follow the moving
  equilibrium and hold where it stops, so it must be firm. At 1000 N/m the arm trails by a few mm. A
  soft profile makes it sag and lag, so it is no longer admittance. Rotation 300 holds the tool
  orientation.
- **The equilibrium is integrated from force, never copied from the arm.** An equilibrium set to
  the measured pose gives zero spring force, and the arm sinks under the gravity residual. That is
  the collapse the threshold give-in once caused. Upstream `lbr_ros2_control/AdmittanceController`
  integrates from the measured joints and assumes a stiff, position-controlled arm, so it is not
  used here.
- **What keeps it safe — none of these limits where the arm may go:**
  - **A leash** (`leash_m`, 3 cm): the equilibrium is never more than this ahead of the arm, so a
    bad force reading can never pull harder than 30 N.
  - **A tare:** the force at rest, about 5 N from the gravity residual, is measured each session
    before the go cue and subtracted.
  - **The runaway monitor** (`free_move_safety`), **speed only** (`max_displacement_m: 0` = no distance
    limit): it aborts to the start if the arm moves faster than 0.7 m/s.
- **No boundary means** the arm can be pushed to the edge of its reach, a joint limit or a singular
  pose — where the CLIK stops and the arm simply stops moving — and into anything near it: the table,
  the chair, its own base. Keep the area clear.
- **What is still felt:** the arm's own inertia and joint friction (as in apple pluck), the damping,
  and the threshold before it starts. The estimate of the hand's force also drifts a little with
  posture, so far from the start some directions can feel slightly assisted or held back.

#### Move Vertical / Move Horizontal — one leg of the maze
Each is the maze's rail fixture with **one straight rail** through the start (`virtual_fixtures.vertical_rail`
or `horizontal_rail`, per-run). The task is in `travel_task`, and all of it is live:

- `threshold_m`: how far out turns the ring red.
- `direction`: `both`, `positive` (up / +Y) or `negative`.
- `require_return`: `false` makes the threshold itself the success.
- `return_tolerance_m`: how close to the start counts as back.

**The ring shows the task.** It holds a state per phase (`ring_cue`, live):

| Phase | Ring |
|---|---|
| from the go cue, travelling out | travel quarters **green** |
| threshold reached, come back | travel quarters **red** (plus `audio_cue_threshold`) |
| success | **blue** (plus `audio_cue_reward`) |
| timeout, and between trials | dark |

`ring_cue.quarters` names the quarters that light: Move Vertical uses `[0, 2]` (up and down),
Move Horizontal `[1, 3]` (left and right), and Free Move all four (green while free to move). Which quarter faces up depends on
how the ring sits on the flange. Light quarter 0 alone once and set the lists to match:
```bash
curl "http://192.168.4.1/segments?factor=4&colors=0,255,0,0"     # quarter 0 green; /off to clear
```
The quarter cues use the board's existing `/segments` endpoint, so **the firmware needs no change**.
They need the **Wi-Fi trigger** (`visual_cue.remote_test_trigger: true`), because the X76 wire carries
one bit, not a pattern.

**Reach and gravity** (IK from the maze start, holding the tool orientation):
- **Sideways is easy:** at ±0.25 m every joint is still ≥ 39° from its limit.
- **Down is easy.**
- **Up is the limit.** The arm nears a singular pose above +0.12 m, and +0.20 m is unreachable.
  Hence the vertical rail is ±0.12 m and the horizontal ±0.15 m, both with a 0.10 m threshold.
- **On the vertical rail nothing holds the arm up** except the load data. An untouched arm sinks a
  few cm and stops; the rail anchors after that settle (`anchor_settle_sec`, during the 4 s quiet
  window). **Check that an untouched arm never reaches the threshold** before a session with a
  subject.

The orchestrator warns at start-up if `threshold_m` is at or beyond the rail end.

#### Before the first session with a subject
1. **Free Move, sign check (T1, hand on the E-stop).** Set `free_move.debug_log_enabled: true`.
   Push the tool gently sideways: **the arm must move with the push.** If it moves against it, stop
   at once; the force frame is wrong.
2. **Free Move, creep and feel.** Leave the arm untouched for 10 s; it must not move. Then move it
   around the space the subject will use, and tune `damping_ns_per_m` and `deadband_n` live.
3. **Move Vertical, gravity.** Let go at the start. The arm must stop well short of the threshold.
4. **Ring.** Confirm the travel quarters really are up/down (or left/right) as seen by the subject.

#### A suggested progression
1. **Free Move:** sessions of free handling, damping lowered as the subject gets confident.
2. **Move Horizontal:** first `require_return: false` (reward at the threshold), then `true`.
3. **Move Vertical:** first `direction: negative` (down only, gravity helps), then `both`.
4. **Maze**, along its own diagnostic ladder: `free_plane` → `single_line` → `maze`.

#### Further pre-training tasks worth adding (not implemented yet)
- **Touch and hold.** The arm holds still; the reward comes for holding the apple (force above a
  level for a time). It teaches contact and needs only the force topic.
- **Wait for go.** The reward is withheld if the arm is moved before the go cue. It teaches the quiet
  window every real experiment starts with.
- **One corner.** An L-shaped, two-rail maze profile (one turn), between the single rails and the
  maze. This needs YAML only.
- **Short pull.** Apple Pluck with a 2–3 cm threshold, raised live as the subject learns. No new code.
- **Automatic staircase.** Raise `threshold_m` by itself after N successes in a row. This is a small
  orchestrator addition.

---

## 6. Software Architecture
The stack separates **hard real‑time physical loops** from **high‑level orchestration**, so that
Python state transitions never compromise the 1000 Hz hardware control loops.

### 6.1 System Overview — data flow
Both paths end in a joint **position command** over FRI, and the **cabinet's Cartesian impedance
provides the compliance**. Every start and recover move sends **joint** setpoints via
`LBRJointPositionCommandController`, and so does the whole apple-pluck / perturb trial. For their
fixture phase, restricted-plane / maze switch to `kuka_clik_controller` and send a fixture-constrained
**Cartesian equilibrium**, which it IKs to joints. Robot state flows *back up* to the Python actions
and the recorder, and the operator drives the orchestrator from the dashboard or a terminal.

```mermaid
flowchart TB
    OPS["Operator<br/>dashboard or terminal"]
    ORCH["<b>Layer 3</b> · Orchestrator node (one per experiment)<br/>+ ExperimentControl: status · pause · live params"]
    ACT["<b>Layer 3</b> · Actions<br/>moves · perturbation · freeze · fixture / maze · monitors · cues"]
    REC["<b>Layer 3</b> · TrialRecorder<br/>CSV + JSON sidecar per trial"]
    KIN["<b>Layer 2</b> · Kinematics<br/>optas FK · tf2 poses"]
    JPC["<b>Layer 1</b> · LBRJointPositionCommandController<br/>joint positions → FRI<br/>apple / perturb, every start / recover move"]
    CLIK["<b>Layer 1</b> · kuka_clik_controller<br/>Cartesian equilibrium → IK → joints<br/>fixture phase (switched in by the orchestrator)"]
    EE["End-effector cue ring"]
    APP["<b>Cabinet · 1000 Hz</b> · LbrImpedanceControlServer (FRI app)<br/>per-axis Cartesian impedance · POSITION mode"]
    ARM["iiwa7 arm"]
    BCAST["<b>Layer 1</b> · Broadcasters<br/>lbr_state · joint_state · force_torque"]

    OPS -- "launch · status · live params · pause" --> ORCH
    ORCH --> ACT
    ORCH -- "events" --> REC
    ACT -. "FK / pose" .-> KIN
    ACT -- "LBRJointPositionCommand" --> JPC
    ACT -- "PoseStamped target_frame" --> CLIK
    ACT -- "cue" --> EE
    JPC -- "joint position cmd (FRI)" --> APP
    CLIK -- "joint position cmd (FRI)" --> APP
    APP <--> ARM
    APP -- "FRI state" --> BCAST
    BCAST -- "LBRState · wrench" --> ACT
    BCAST -- "LBRState (cabinet clock)" --> REC

    classDef l3 fill:#e8f0fe,stroke:#4a6fd0,color:#111
    classDef l2 fill:#eef7ee,stroke:#4a9a4a,color:#111
    classDef l1 fill:#fff4e5,stroke:#d08a2a,color:#111
    classDef hw fill:#f3e8fd,stroke:#8a4ad0,color:#111
    class ORCH,ACT,REC l3
    class KIN l2
    class JPC,CLIK,BCAST l1
    class APP,ARM,EE hw
```

Blue: Layer 3, orchestration (Python). Green: Layer 2, kinematics (Python). Orange: Layer 1,
real-time control (C++, ros2_control). Purple: hardware.

The actions, one by one, are in the [§6.2 table](#62-composition--the-launch-brings-up-hardware-the-orchestrator-runs-the-experiment).
The visual cue currently fires over the ring's Wi-Fi (a test trigger); the X76 wire is planned
([§6.7](#67-end-effector-board--the-visual-cue)).

> **Where the "feel" is decided.** The fixture geometry (Python) says *where* the walls are; the
> cabinet's **per-axis stiffness** says *how firm* they are; and the **tracking clamps**
> (`kuka_clik_controller.max_linear_velocity`, `virtual_fixtures.max_target_step_m`) decide whether the
> allowed region feels free. All three must be set together — see the note in section 5.

### 6.2 Composition — the launch brings up hardware, the orchestrator runs the experiment
The codebase keeps a hard line between **hardware bring‑up** and **experiment logic**, and that line
*is* the launch ↔ orchestrator boundary:

```mermaid
flowchart LR
    D["dashboard or terminal"] -- "ros2 launch<br/>[params_file:=…]<br/>[clik_nullspace_cfg:=…]" --> L["iiwa7_*.launch.py<br/>(thin per-experiment wrapper)"]
    L --> B["experiment_base.launch.py<br/>(shared)"]
    B --> HW["iiwa7_hardware.launch.py<br/>FRI client · ros2_control<br/>robot_state_publisher · controller spawners"]
    B --> O["orchestrator node<br/>trial state machine"]
    O --> A["actions<br/>(moves · monitors · cues · controller switch)"]
    O --> C["ExperimentControl<br/>status · pause · live params · NSP hook"]
    O --> R["TrialRecorder<br/>(not restricted-plane)"]
```

- **Launch files own the hardware.** Every experiment launch is a *thin wrapper* (~25 lines) over one
  shared [`experiment_base.launch.py`](sinthlab_bringup/launch/experiment_base.launch.py), which does
  the identical hardware setup for every experiment: build the `robot_description`, include
  `iiwa7_hardware.launch.py` (FRI client + `ros2_control` + broadcasters), and start the
  orchestrator. A wrapper supplies only the three things that differ — the **config YAML**, the
  **orchestrator** to run, and the **controllers**: `lbr_joint_position_command_controller` is always
  the ACTIVE one, and the fixtures additionally load `kuka_clik_controller` INACTIVE for the
  orchestrator to switch to.

- **The orchestrator owns the ROS side.** Each experiment has exactly one orchestrator node (1:1 with
  its launch) that builds the experiment's **trial state machine** (Move Vertical and Move Horizontal
  share `rail_training_orchestrator`, configured by their YAML). The orchestrators are kept
  **independent** (no shared base) so each reads top‑to‑bottom as one self‑contained experiment.

- **Orchestrators are composed only of actions.** An orchestrator holds no inline robot logic; it is a
  wiring of reusable **action** objects, each with a uniform `start()` → `on_complete` shape, chained
  by callbacks. Changing a step means swapping an action, not rewriting the node:

  | Action | Responsibility |
  |--------|----------------|
  | `MoveToPositionJointSpace` | drive to an absolute joint target (FRI position cmd). Used for every start / recover move |
  | `PerturbInitialPosition` | polar (r, θ) perturbation from the start pose (joint‑space DLS‑IK) |
  | `FreezeAtPoseAction` | at the snap, move the equilibrium onto the arm and hold it there (apple / perturb) |
  | `SwitchControllerAction` | switch between the joint controller and `kuka_clik_controller` (restricted-plane / maze) |
  | `MoveRestrictedOnAPlaneAction` / `MoveInMazeAction` | stream the fixture‑constrained equilibrium to `kuka_clik_controller` |
  | `CartesianImpedanceDisplacementMonitor` | baseline → displacement threshold → snap → hold for the dwell → complete |
  | `CheckpointMonitor` | maze checkpoints (reward once each, any order) and the goal |
  | `AdmittanceMoveAction` | Free Move: moves the equilibrium at force ÷ damping, leashed to the arm; no boundary |
  | `TravelMonitor` | Move Vertical / Horizontal: travel ≥ threshold, then (optionally) back at the start |
  | `SafetyStopMonitor` | runaway backstop: too far or too fast → abort to recovery (restricted-plane / maze / pre-training). Free Move runs it speed-only (`max_displacement_m: 0`) |
  | `ForceReleaseWaiter` | wait until the operator lets go (external force ≈ 0) before the maze or a pre-training task recovers |
  | `AudioCue` / `VisualCue` / `WaitAction` | tone cue / NeoPixel ring cue / one‑shot delay |
  | `RingStateCue` | pre-training: holds a quarter-ring state (green / red / blue / dark) via the board's `/segments` |
  | `TrialRecorder` (helper) | one CSV + JSON sidecar per trial ([§7](#7-data-collected)) |
  | `ExperimentControl` (helper) | outside control: `<ns>/experiment_status` (JSON, latched), `<ns>/<orchestrator>/pause`, the live-parameter gate, and the NSP event hook |

  **Outside control.** Every orchestrator creates one
  [`ExperimentControl`](sinthlab_bringup/sinthlab_bringup/helpers/experiment_control.py) and ends each
  trial with `control.begin_trial(self.start_trial)` rather than calling `start_trial()` directly.
  That call is where a pause holds the arm at the start, and where accepted live-parameter changes
  are applied: `_reload_live()` calls `reload()` on the cue, monitor and perturbation actions. So a
  change never lands mid-trial. A trial with no natural end (Free Move) also registers
  `control.on_pause_request(...)`: a pause request — the dashboard's Pause or Stop after trial — ends
  its session at once, so it reaches that trial boundary instead of never getting there. The dashboard ([`experiment_ctrl_gui/`](experiment_ctrl_gui/README.md))
  is built on these interfaces, and anything else can use them too.

  **Starting from a straight arm.** At mechanical zero the arm is fully straight, which is singular:
  the Jacobian's smallest singular value is **0.0**, so the cabinet's Cartesian impedance cannot act in
  some directions and a ROS move commanded from there does not reliably reach its target. The **Sunrise
  app** handles this before ROS is involved. When it starts with

  ```
  max(|A2|, |A4|, |A6|) < 12 deg        ->  arm is nearly STRAIGHT (singular)
  ```

  it asks on the SmartPad, then PTPs the arm to the ready pose `[0, 10, 0, −80, 0, 90, 0]` in plain
  position control, and only then opens FRI and switches impedance on. So every experiment's first move
  starts from a well-conditioned posture, and ROS needs no start-up special case. The bend test agrees
  exactly with "smallest singular value < 0.05", including the *extended-but-rotated* case (A1 = 90°
  but the arm straight) that a "distance from mechanical zero" test would miss. Every experiment start
  bends one of A2/A4/A6 by 36° or more, so an arm parked at a start pose is not moved.

  A trial is then literally a chain of actions — e.g. apple‑pluck:
  `move_to_start → quiet_window → audio_cue → monitor → (snap cue) → move_recover → repeat`.

### 6.3 Hardware Bring‑up Sequence
Controllers are spawned in a deliberate order: `joint_state_broadcaster` first (it needs no URDF
and proves the controller_manager has received the robot description), then the controllers that
parse the URDF in `on_init()`.

```mermaid
sequenceDiagram
    actor Op as Operator
    participant CAB as KUKA cabinet (SmartPad)
    participant ROS as ros2 launch (dashboard ▶ Start, or terminal)
    participant CM as controller_manager
    participant ORCH as Orchestrator

    Op->>CAB: Start LbrImpedanceControlServer, pick the scenario's stiffness profile
    opt arm nearly straight (max |A2,A4,A6| < 12°)
        CAB->>Op: SmartPad: move to the ready pose?
        Op->>CAB: Move to ready pose (hold enabling switch)
        CAB->>CAB: joint PTP to [0, 10, 0, −80, 0, 90, 0] in position control
    end
    Note over CAB: opens FRI, waits ~60 s for the FRI client
    Op->>ROS: ros2 launch sinthlab_bringup iiwa7_*.launch.py
    ROS->>CM: start ros2_control_node (FRI client) + robot_state_publisher
    CM-->>CAB: FRI session → COMMANDING_ACTIVE
    ROS->>CM: spawn joint_state_broadcaster
    Note over CM: its spawner exits only once it is ACTIVE,<br/>i.e. the URDF has been received
    ROS->>CM: spawn estimated_wrench_interface · lbr_state_broadcaster ·<br/>force_torque_broadcaster · lbr_joint_position_command_controller
    opt restricted-plane / maze
        ROS->>CM: spawn kuka_clik_controller INACTIVE
    end
    ROS->>ORCH: start orchestrator (after startup_delay, default 0 s)
    ORCH->>ORCH: wait for the first lbr_state, then trial 1 → move to start
    ORCH-->>Op: experiment_status (dashboard status card)
```

### 6.4 Layers
**Layer 1 — Real‑time control (C++ / ros2_control)**
- **Cabinet‑side Cartesian impedance (`LbrImpedanceControlServer`):** the KUKA cabinet runs the
  Cartesian‑impedance virtual spring at 1000 Hz with a **per‑axis** `{X,Y,Z,A,B,C}` stiffness diagonal,
  so it can enforce axis‑aligned fixtures in hardware (lock a plane, firm walls on the free axes). ROS
  only streams the equilibrium to it.
- **`LBRJointPositionCommandController` (lbr_ros2_control):** the **apple‑pluck / perturb** controller
  — forwards joint positions straight to the FRI position command (no IK). Typed message
  `lbr_fri_idl/LBRJointPositionCommand` on `…/command/lbr_joint_position_command`.
- **`kuka_clik_controller` (IDRA Lab, vendored):** the **restricted‑plane / maze** controller — a
  Closed‑Loop IK tracker that converts the fixture's Cartesian equilibrium into joint commands. Message
  `geometry_msgs/PoseStamped` on `…/kuka_clik_controller/target_frame`. Its `max_linear_velocity` caps
  how fast that equilibrium may chase the operator's hand and is the main "does the fixture feel free"
  knob.

**Layer 2 — Kinematics math (Python)**
- **`optas`:** used inside the Python actions for fast Forward Kinematics (FK) and analytical
  Jacobian conversions, avoiding singular‑matrix crashes when reading Cartesian poses or mapping
  forces.

**Layer 3 — State‑machine orchestration (Python)**
The experimental flows are orchestrated by high‑level `rclpy` nodes (one per experiment), each
composed entirely of the modular actions catalogued in §6.2 — `MoveToPositionJointSpace`,
`PerturbInitialPosition`, `FreezeAtPoseAction`, `SwitchControllerAction`,
`MoveRestrictedOnAPlaneAction` / `MoveInMazeAction`, the monitors, `AudioCue`, `VisualCue`, `WaitAction` —
plus `TrialRecorder` and `ExperimentControl`. The per‑scenario flows are below.

### 6.5 Control rates — why a 1000 Hz spring but a 10 ms FRI period
The cabinet's control loop and the FRI network exchange run on **two different clocks** — don't
conflate them:

| Clock | What it does | Rate |
|---|---|---|
| **Cabinet control loop** | Computes the Cartesian‑impedance law (`F = K·(x_target − x) − D·v`) and applies joint torques. | **1 ms (1000 Hz)** — fixed by KUKA Sunrise |
| **FRI send period** | Network packet exchange with the ROS client: ROS pushes a new **equilibrium** (joint positions for apple‑pluck, a Cartesian pose for restricted‑plane) and reads back state. | **10 ms (100 Hz)** — you pick 1 / 2 / 5 / 10 ms |

So selecting **10 ms does not slow the spring down.** The cabinet keeps evaluating the impedance
physics every 1 ms against the latest equilibrium; FRI only refreshes the *target* (the spring's
anchor) and the *feedback* 100×/second.

**Between FRI packets**, the cabinet holds the last commanded equilibrium and runs the 1 kHz loop
against it, smoothing the stepwise 10 ms updates via `joint_position_tau` (a 40 ms EMA in
`lbr_system_config.yaml`) so the arm doesn't jerk. Because the target moves slowly (a start pose, a
gentle pull), a 100 Hz anchor refresh is plenty — the 1 kHz loop fills in the dynamics.

**Why 10 ms and not 1 ms?** The FRI send period is a hard deadline the *client* must meet; miss it
and the session drops out of `COMMANDING_ACTIVE` and the robot stops. The client is ROS 2 on
**WSL2 — not a real‑time OS** — over a jittery ethernet link, so reliably hitting a 1–2 ms deadline
is impractical while 10 ms is robust. It also matches the ROS rate (`controller_manager`
`update_rate: 100` in `config/iiwa7_hardware_controllers.yaml`) — no point sending faster than ROS produces
commands.

This decoupling is the whole reason the impedance lives **on the cabinet**: the fast,
safety‑critical loop stays at 1 kHz on a real‑time controller, while the slow, non‑real‑time ROS
link only streams a position target at 100 Hz. Running the impedance in ROS instead would pin the
spring law to that ~100 Hz link — far coarser and riskier for torque control.

### 6.6 Experiment State Flows
Each flow is one trial. The event token each step logs is in brackets (see [§7](#events-per-experiment)).
Every trial ends in `control.begin_trial(...)`: it applies any pending live changes, then starts the
next trial, or holds at the start if a pause was requested. Free Move's session only ends when a pause
is requested (or after `session_sec`), so for it a pause means "end the session now" (Flow 6).

**Flow 1 — Apple Pluck** (joint controller throughout)
```mermaid
stateDiagram-v2
    [*] --> MoveToStart : [trial_start]
    MoveToStart --> QuietWindow : at start [at_start]
    QuietWindow --> GoCue : quiet_window_sec (2 s) [quiet_end]
    GoCue --> Monitor : audio + visual cue [cue_go]
    Monitor --> Snap : baseline locked [armed]<br/>pull ≥ threshold (0.1 m, norm) [snap]
    Snap --> Hold : snap cue [cue_snap], freeze the equilibrium on the arm [freeze]
    Hold --> Recover : force_release_shutdown_delay_sec (0.8 s) [recover_start]
    Recover --> NextTrial : apple back within 3 cm [trial_end]
    NextTrial --> MoveToStart : next trial
    NextTrial --> Paused : pause requested
    Paused --> MoveToStart : resume
```

**Flow 2 — Restricted Plane** (joint moves, CLIK fixture). No TrialRecorder; the fixture action writes
its own trajectory CSV.
```mermaid
stateDiagram-v2
    [*] --> MoveToStart : [trial_start]
    MoveToStart --> SwitchToCLIK : at start [at_start]
    SwitchToCLIK --> QuietWindow
    QuietWindow --> GoCue : quiet_window_sec [cue_go]
    GoCue --> Fixture : fixture + monitor + safety on [armed]
    note right of Fixture
      Projects the measured pose onto the active
      fixture (sine rail by default) and streams it
      as the cabinet-impedance equilibrium.
    end note
    Fixture --> Snap : pull ≥ threshold (0.5 m, z) [snap]<br/>fixture off, snap cue
    Snap --> SwitchToJoint : dwell (force_release_shutdown_delay_sec)
    Fixture --> SwitchToJoint : SAFETY trip — too far / too fast [safety_trip]
    SwitchToJoint --> Recover : [recover_start]
    Recover --> NextTrial : [trial_end]
    NextTrial --> MoveToStart : next trial (or hold if paused)
```

**Flow 3 — Apple Pluck Perturb** (joint controller throughout). The cue comes **before** the
perturbation: the monkey starts reaching, then the apple is displaced.
```mermaid
stateDiagram-v2
    [*] --> MoveToStart : [trial_start]
    MoveToStart --> QuietWindow : at start [at_start]
    QuietWindow --> GoCue : quiet_window_sec [quiet_end]
    GoCue --> PerturbDelay : audio + visual cue [cue_go]
    PerturbDelay --> Perturb : start_delay_sec (1.5 s) [perturb_delay_start]
    Perturb --> Monitor : polar (r, θ) move done [perturb_applied]
    Monitor --> Snap : settle baseline_settle_sec (1 s) [armed]<br/>pull ≥ threshold [snap]
    Snap --> Hold : snap cue, freeze [freeze]
    Hold --> Recover : dwell [recover_start]
    Recover --> NextTrial : apple back within 3 cm [trial_end]
    NextTrial --> MoveToStart : next trial (or hold if paused)
```

**Flow 4 — Maze** (joint moves, CLIK fixture)
```mermaid
stateDiagram-v2
    [*] --> MoveToStart : [trial_start]
    MoveToStart --> SwitchToCLIK : at start [at_start]
    SwitchToCLIK --> QuietWindow : [fixture_active]
    QuietWindow --> GoCue : quiet_window_sec [cue_go]
    GoCue --> Maze : rails + checkpoints + timeout + safety on [maze_armed]
    Maze --> Maze : checkpoint reached → reward cue [checkpoint]
    Maze --> ReleaseWait : goal [goal] or timeout_sec [timeout]<br/>fixture off, goal / timeout cue [release_wait]
    ReleaseWait --> SwitchToJoint : operator lets go [released]
    Maze --> SwitchToJoint : SAFETY trip — no cue, no wait [safety_trip]
    SwitchToJoint --> Recover
    Recover --> NextTrial : [trial_end]
    NextTrial --> MoveToStart : next trial (or hold if paused)
```

**Flow 5 — Move Vertical / Move Horizontal** (joint moves, CLIK with one rail)
```mermaid
stateDiagram-v2
    [*] --> MoveToStart : [trial_start]
    MoveToStart --> SwitchToCLIK : at start [at_start]
    SwitchToCLIK --> QuietWindow : rail anchors [fixture_active]
    QuietWindow --> Out : quiet_window_sec, ring green [cue_go]<br/>monitor + timeout + safety on [armed]
    Out --> Back : travel ≥ threshold_m, ring red [threshold]
    Back --> ReleaseWait : back at the start, reward [goal]
    Out --> ReleaseWait : timeout_sec [timeout]
    ReleaseWait --> SwitchToJoint : hand lets go [released]
    Out --> SwitchToJoint : SAFETY trip [safety_trip]
    Back --> SwitchToJoint : SAFETY trip [safety_trip]
    SwitchToJoint --> Recover
    Recover --> NextTrial : [trial_end]
    NextTrial --> MoveToStart : next trial (or hold if paused)
```
With `require_return: false`, `threshold` and `goal` fire together.

**Flow 6 — Free Move** (joint moves, CLIK with admittance; no goal)
```mermaid
stateDiagram-v2
    [*] --> MoveToStart : [trial_start]
    MoveToStart --> SwitchToCLIK : at start [at_start]
    SwitchToCLIK --> QuietWindow : hold, measure the resting force (tare) [fixture_active]
    QuietWindow --> Free : quiet_window_sec, ring green [cue_go]<br/>admittance + speed monitor on [armed]
    Free --> ReleaseWait : Pause / Stop after trial (or session_sec), end tone, the arm holds [session_end]
    ReleaseWait --> SwitchToJoint : hand lets go [released]
    Free --> SwitchToJoint : SAFETY trip (too fast) [safety_trip]
    SwitchToJoint --> Recover
    Recover --> NextTrial : [trial_end]
    NextTrial --> MoveToStart : holds at the start (paused) or the launch stops; Resume = new session
```

### 6.7 End-effector board — the visual cue

The [apple‑pluck end effector](end_effector_design/README.md) carries its own microcontroller, an
**Adafruit Metro M4 AirLift**, which drives the 60‑LED RGBW **NeoPixel ring** on the cover as a
**visual cue** for the subject. Its CircuitPython firmware lives in
[`end_effector_metro_code/`](end_effector_metro_code/README.md).

**The cue is on and off with a timer.** The board runs its configured cue whenever **X76 contacts 1
and 2 are shorted** at the robot base; the short travels up through the media flange to the tool
connector and pulls the board's `D2` low:

```
   switch at robot base ── X76 contacts 1/2 ══ media flange ══ tool pins 9/10 ──► Metro D2
                                                                                  ring on, then off
```

**Power reaches the effector the same way:** the cabinet's 24 V comes down the X650/X651 data cable
to **tool pins 1/2**, into the Tobsun converter, down to the 5 V rail. Full pinout in
[`end_effector_design/README.md`](end_effector_design/README.md#tool-connector-pinout).

**The cabinet does not trigger the cue.** This arm has the **Media flange Inside electric**, a
pass‑through with no cabinet‑driven I/O, and the Sunrise project has no generated I/O groups
(`src/com/kuka/generated/` does not exist). The Sunrise application plays no part in the cue.

**The wire path is an RS‑422 serial link — decided, parts on order.** The effector casing opens, so
firmware can be redeployed, and the force/pressure sensor needs a data channel off the tool anyway; one
full-duplex differential link carries both the cue trigger and the sensor data. A dry-contact relay on
X76 1–2 would be **redundant and two orders of magnitude slower** — a mechanical contact is 5–15 ms
against ~80 µs of wire time.

| | |
|---|---|
| ROS box | **StarTech ICUSB422IS** — isolated USB↔RS‑422, 2500 Vrms, FTDI FT232RL |
| Tool | **MIKROE‑2821 RS485 3 Click** — SN65HVD31, full duplex, 3.3 V |
| Link | shielded twisted pair on the CTR pairs through the flange |

Notes:

- **No optocoupler on the inbound path.** The only voltage in the trigger loop is the Metro's own
  3.3 V through D2's pull‑up; a floating contact has nothing to isolate. The *outbound* direction is
  different — anything the Metro drives toward a 24 V cabinet input does need one.
- **`latency_timer` must be set to 1.** FTDI defaults to 16 ms of buffering, which would hand back
  exactly the delay the serial link was chosen to avoid. See §8.
- **Until the link is fitted, the experiments run unchanged.** [`VisualCue`](sinthlab_bringup/sinthlab_bringup/actions/visual_cue.py)
  is called beside `AudioCue` at all eight cue sites. On the wire path it is a **safe no‑op**: it
  completes immediately and warns once if `visual_cue.enabled` is true.
- **When the link is up,** implement `VisualCue._close_switch()` as a serial write
  and set `visual_cue.remote_test_trigger: false`. If the arm box runs WSL2, the adapter needs
  `usbipd-win attach`.

> **Worth building at the same time: a firmware echo.** The link is full duplex, so the Metro can
> write an ack **at the moment it calls `pixels.show()`**. That turns cue delivery from unmeasured
> into a per‑trial timestamp accurate to ~2 ms, with no extra hardware — which is what cue‑locked
> neural analysis needs. The firmware already has the right shape: `cue_start()` lights the ring
> *before* the `/cue` handler returns, so the existing Wi‑Fi RTT already brackets the light.

**For demos and recordings, fire the cue over Wi‑Fi instead — no wire needed.** In the
experiment's YAML set:

```yaml
visual_cue:
  enabled: true                 # on in the apple pluck, perturb and maze configs
  remote_test_trigger: true
  colours:                      # optional, per cue site: [r, g, b, w]
    play: [0, 255, 0, 0]        # trial start: green
    snap: [255, 0, 0, 0]        # threshold reached: red
```

Then join the ROS computer to the board's **`KUKA_NEOPIXEL`** Wi‑Fi (its Ethernet link to the
robot is separate) and check the link from the shell you launch from:
`curl http://192.168.4.1/status`. Each cue site sends `GET http://192.168.4.1/cue` — the same as
running that `curl` by hand — from a background thread, so a slow or missing board never stalls a
trial. Every cue is logged with its round‑trip time, and a failed one says why. Each cue site can carry its own colour (`visual_cue.colours`): green at trial start, red at threshold, goal and timeout, blue for maze rewards. **Not for
experiments:** the Wi‑Fi delay varies from cue to cue, so never align trial data to it. Code:
[`visual_cue_remote.py`](sinthlab_bringup/sinthlab_bringup/actions/visual_cue_remote.py).

**Quarter-ring states (pre-training).** The pre-training tasks do not flash a cue; they *hold* a
state on the ring — chosen quarters green while travelling, red at the threshold, blue on success,
dark otherwise — with the board's `/segments` endpoint, over Wi-Fi only. See
[Pre-training](#pre-training--free-move-move-vertical-move-horizontal).

#### Changing what the cue looks like

**On the board, not in ROS**, apart from a per‑event colour for Wi‑Fi cues (`visual_cue.colours`
above). Brightness, pattern, segments, duration, rate and the default colour live **on the board** and
are set over the board's **own Wi‑Fi access point**:

1. Join **`KUKA_NEOPIXEL`** from a laptop or phone (the board hosts it; it never joins another
   network). The board is always at **`192.168.4.1`**.
2. Call `/config` with any subset of settings — unsent fields are unchanged:
   ```bash
   curl "http://192.168.4.1/config?r=0&g=255&b=0&w=0&pattern=segment&segments=6&duration=1.2"
   curl  http://192.168.4.1/cue              # try it, no robot needed
   curl "http://192.168.4.1/config?save=1"   # keep it across reboots
   curl  http://192.168.4.1/status           # read everything back, incl. the live trigger pin
   ```
3. **`brightness` (0.0–1.0) is not capped in firmware.** At 1.0 the 60‑LED ring can draw up to
   **~4.8 A at 5 V**; the default `0.2` is a conservative starting point, not a measured limit for
   your build. Before raising it, check the converter rating, the 5 V wiring gauge, that 5 V is
   injected at all four quarter‑ring joints, and the temperature inside the casing — the effector
   is handled by an animal. The
   [power section](end_effector_metro_code/README.md#power--read-before-raising-brightness) has
   the per‑colour current table.

The split is deliberate: the trigger line is **one bit** and cannot carry a colour, and an
experiment cue must not depend on a radio link. So the switch says *when*, and the board — already
configured by hand — decides *what*. The Wi‑Fi test trigger adds only a colour per event: pattern, duration and brightness stay a
commissioning step.

> **Full settings reference, wiring, patterns, and the commissioning order are in
> [`end_effector_metro_code/README.md`](end_effector_metro_code/README.md).**

---

## 7. Data Collected

### One CSV + one JSON sidecar per trial, for every experiment

Verified on hardware 2026-09-23: 100 Hz, clean cabinet clock, all 10 apple-pluck events captured in
order, every trial passing `validate_recording.py`. Every column is defined in the data dictionary
below.

| | Apple pluck | Perturb | Maze |
|---|---|---|---|
| Columns | **42** | **42** | **47** |
| Extra over the core | `disp_m` | `disp_m` | `rel_a` `rel_b` `corridor` `off_rail` `rail_dist` `rail_nearest` |
| Events | 10 | 12 | 12 |
| Sidecar extras | `threshold_m` | `perturbation` | `maze_geometry` |
| Size | 2.9 MB/min | 2.9 MB/min | 3.2 MB/min |

**The 41-column core**

| Block | Cols | Contents |
|---|---|---|
| Time | 5 | `t`, `t_wall`, `t_ros`, **`fri_s`, `fri_ns`** |
| EE pose | 7 | `x y z` + quaternion |
| Joints | 21 | `meas_A1..A7`, `cmd_A1..A7`, `ext_A1..A7` — rad and Nm |
| FRI health | 6 | `tracking`, `session`, `quality`, `safety`, `drive`, `control` |
| Events | 2 | `event`, `event_arg` |

Why each earns its place:

- **`fri_s`/`fri_ns`** is the cabinet's own clock — the anchor for aligning to the Blackrock NSP.
- **The quaternion** captures the apple's orientation, so an off-axis pull is measured.
- **`cmd − meas`** is the impedance droop — under Cartesian impedance the arm lags its equilibrium by
  `F / k`, and that lag is signal, not error. A steady offset at rest points at un-modelled tool mass.
- **`ext_A1..A7`** measures a pull with no force sensor fitted.
- **FRI health per sample** makes a bad trial self-diagnosing.
- **`disp_m`** (pluck/perturb) is the dependent variable of the experiment. Recording it per sample is
  also what lets the threshold crossing be interpolated to sub-millisecond, which the 10 ms cabinet
  stamp cannot give on its own.

### Events, per experiment

#### Apple pluck

**Records from** `start_trial()` **to** `on_recover_complete()` — the whole trial including the
return to start, not just the pull.

**Extra column (1):** `disp_m` — displacement from the locked baseline, computed by
`CartesianImpedanceDisplacementMonitor` every tick. **The dependent variable of the experiment.**

**Events**, in trial order. Some callbacks mark more than one event:

| Orchestrator callback | `event` | `event_arg` | Marked when |
|---|---|---|---|
| `start_trial()` | `trial_start` | trial index | the trial begins; the move to start is sent |
| `on_move_complete()` | `at_start` | — | the arm has reached the start pose |
| `on_quiet_window_complete()` | `quiet_end` | — | the quiet window has elapsed |
| `on_quiet_window_complete()` | `cue_go` | — | the audio + visual go cues have been fired |
| `on_monitor_armed()` | `armed` | — | the baseline is locked; the animal may pull |
| `on_monitor_snap()` | `snap` | **displacement, m** | the pull crosses the threshold |
| `on_monitor_snap()` | `cue_snap` | — | the snap cues have been fired |
| `on_monitor_snap()` | `freeze` | — | the equilibrium is frozen on the arm (`freeze_hold.start()`) |
| `on_monitor_complete()` | `recover_start` | — | the hold has elapsed; the move back to start begins |
| `on_recover_complete()` | `trial_end` | trial index | the arm is back at the start |

**Cue delivery events** (all three experiments, fired from the cue classes rather than the state
machine, so they can appear anywhere and more than once):

| Event | Fired when | `event_arg` | Observed or inferred? |
|---|---|---|---|
| `cue_visual_ack` | the board answers a Wi-Fi cue | round trip, ms | **observed** — the firmware calls `pixels.show()` *inside* the `/cue` handler and answers afterwards, so an ack means the ring is already lit |
| `cue_audio_end` | the beep subprocess exits | process lifetime, s | **observed** — `[console]::Beep` blocks for exactly `duration_ms`, so the sound's START is `end − duration_ms` |

These exist because `AudioCue.on_complete` fires when `Popen` *returns* — about 49 ms in on WSL2,
and roughly 290 ms before any sound (the Windows process takes ~340 ms to spawn). Nothing else in
the system observes either cue, so without these the record cannot say when the animal was cued.

`armed` is the one that matters behaviourally — it is the moment the baseline locks and the animal
may pull. Reaction time is `snap − armed`.

#### Perturb

Identical to apple pluck, plus two events between `cue_go` and `armed`:

| Orchestrator callback | `event` | `event_arg` | Marked when |
|---|---|---|---|
| `on_audio_complete()` | `perturb_delay_start` | delay, s | the go cue is out; the wait before the perturbation starts |
| `on_perturb_complete()` | `perturb_applied` | magnitude, m | the perturbation move has finished |

`armed` then comes after the monitor's settle (`baseline_settle_sec`), so the baseline is the
post-perturbation rest pose.

The applied perturbation **vector** is constant within a trial and goes in the sidecar, not in a
column.

#### Maze

**Records from** `start_trial()` **to** recover complete — the approach and the settle included, not
just the maze phase.

**Extra columns (6):** `rel_a`, `rel_b`, `corridor`, `off_rail`, `rail_dist`, `rail_nearest`

**Events:**

| Orchestrator callback | `event` | `event_arg` |
|---|---|---|
| `start_trial()` | `trial_start` | trial index |
| `on_move_complete()` | `at_start` | — |
| `on_switched_to_fixture()` | `fixture_active` | — |
| `on_quiet_window_complete()` | `cue_go` | — |
| `on_go_complete()` | `maze_armed` | — |
| `on_checkpoint_reward(i)` | `checkpoint` | **index** |
| `on_goal_reached()` | `goal` | — |
| `on_timeout()` | `timeout` | — |
| `on_safety_trip(reason)` | `safety_trip` | reason code |
| `force_release.start()` | `release_wait` | — |
| force release complete | `released` | — |
| recover complete | `trial_end` | trial index |

`off_rail` transitions stay a column rather than events — it toggles too often to be useful as one.

#### Pre-training

**Records from** `start_trial()` **to** recover complete, like the maze.

**Extra columns:** Move Vertical / Move Horizontal have the maze's six (`rel_a` … `rail_nearest`).
Free Move has six of its own: `eq_dx`, `eq_dy`, `eq_dz` (the commanded equilibrium minus the start,
base frame, m) and `f_adm_x`, `f_adm_y`, `f_adm_z` (the force that moved it: tared, filtered and
past the threshold, base frame, N).

**Events:**

| Orchestrator callback | `event` | `event_arg` |
|---|---|---|
| `start_trial()` | `trial_start` | trial index |
| `on_move_complete()` | `at_start` | — |
| `on_switched_to_fixture()` | `fixture_active` | — |
| `on_quiet_window_complete()` | `cue_go` | — |
| `on_go_complete()` | `armed` | — |
| `on_threshold(d)` | `threshold` | **travel [m]**, signed along the rail (rails only) |
| `on_success()` | `goal` | — (rails only) |
| `on_timeout()` | `timeout` | — (rails only) |
| `on_end_requested()` / `on_session_over()` | `session_end` | — (Free Move only: Pause / Stop after trial, or `session_sec`) |
| `on_safety_trip(reason)` | `safety_trip` | reason code |
| `force_release.start()` | `release_wait` | — |
| force release complete | `released` | — |
| recover complete | `trial_end` | trial index |

---

### The cabinet clock, measured

`check_clock_drift.py` on the real arm, 29 996 samples over 300 s:

| | |
|---|---|
| Populated | yes — real Unix epoch |
| Resolution | **quantised to 10.000 ms**, exactly the FRI sample period |
| Sample spacing | median 10.000 ms, **p99 10.000 ms** |
| Drift vs the ROS box | **< 0.1 ppm** |
| Discontinuities | none |
| Absolute offset | ~15 min ahead — **harmless**, it is the *rate* that matters |

The stamp is an exact, jitter-free **sample grid**, not a free-running clock. It says which sample
with no ambiguity; sub-sample event timing comes from interpolating the signal, not from reading the
clock. Drift is a non-issue — an hour accumulates under 0.4 ms.

### Cue delivery is measured, not assumed

`AudioCue.on_complete` fires when `Popen` **returns** — about 49 ms in on WSL2, and roughly **290 ms
before any sound** (the Windows process takes ~340 ms to spawn). Audio and visual therefore fire in
the same callback but arrive ~340 ms apart. Two events close that gap:

| Event | Fired when | Arg | |
|---|---|---|---|
| `cue_audio_end` | the beep process exits | lifetime, s | **observed** — `[console]::Beep` blocks for exactly `duration_ms`, so the sound's START is `end − duration_ms` |
| `cue_visual_ack` | the board answers a Wi-Fi cue | round trip, ms | **observed** — the firmware calls `pixels.show()` *inside* the `/cue` handler and replies after, so an ack means the ring is already lit |

There is **no photodiode and no microphone**. Robot events (snap, checkpoints, goal) align to neural
data well under 10 ms; cue-locked analysis still depends on the two markers above, or on the firmware
echo described in §6.7.

### Sync to the Blackrock NSP

The hook is wired and waiting for the DIO. Every orchestrator passes
`TrialRecorder(..., on_event=self.control.on_event)`, and `mark()` calls it **synchronously, before
anything else**, so a pulse leaves at the same instant the event is logged. There is one call site,
so the two cannot drift apart in a later edit. The codes are in
[`helpers/experiment_control.py`](sinthlab_bringup/sinthlab_bringup/helpers/experiment_control.py):

```python
NSP_CODES = {"trial_start": 1, "at_start": 2, "armed": 3, "snap": 4,
             "checkpoint": 5, "goal": 6, "timeout": 7, "safety_trip": 8, "trial_end": 9,
             "threshold": 10, "session_end": 11}
```

Sending is switched by **`nsp_sync.enabled`** in each experiment YAML. It is a live parameter, so the
dashboard can toggle it between trials. Until the DIO arrives, `ExperimentControl._pulse()` warns
once that nothing is being sent. When the DIO arrives, implement the pulse in `_pulse()`; nothing
else changes.

**Two pulses per trial are enough.** One at each end gives offset *and* local rate; every other event
is already in the CSV on the cabinet clock, so the fitted map carries them along for free. Send a
*code* rather than a bare pulse so each one self-identifies — a dropped pulse then shows up instead
of silently mispairing every subsequent trial.

### The sidecar

Everything constant within a trial: experiment, trial index, session and subject id, all four clocks
sampled together at trial start **and** end, FRI state, active controllers, git SHA, start pose,
baseline, perturbation, maze geometry, and the full resolved parameter dump.

Two fields worth knowing:

- **`events`** — every `mark()` with the moment it *actually* happened (`t`, `t_wall`, `t_ros`,
  `fri_s`, `fri_ns`) and the CSV row it landed on. The CSV column is quantised to the 10 ms grid;
  this is not. Use the column to **find** an event, the sidecar to **time** it. This is what a TTL
  pulse lines up against.
- **`partial`** — true until the trial completes. The sidecar is written at `start()` and kept current
  on every event, so an interrupted trial still has one and identifies itself rather than looking
  like a finished trial with events missing.

- **`maze_geometry`** embeds the corridors as they were *at record time*. Without it a six-month-old
  run silently plots against whatever `maze_params.yaml` says today.

### Data dictionary

Every column, what it holds and where it comes from. `LBRState` fields are copied straight from
`<ns>/lbr_state`; "derived" means the recorder computes it.

#### Time (all experiments)

| Column | Unit | Source | Meaning |
|---|---|---|---|
| `t` | s | derived | Seconds since the recorder started. Convenience axis for plotting; **not** an alignment clock. |
| `t_wall` | s (Unix epoch) | `time.time()` on the ROS box | Absolute wall time at the moment the callback ran. Use to correlate with video files — but see the clock section below: the ROS box clock was measured ~3 min off. |
| `t_ros` | s | `node.get_clock().now()` | ROS clock. Matches TF stamps, so it is the right clock for reasoning about anything ROS-side. |
| `fri_s` | s (Unix epoch) | `LBRState.time_stamp_sec` | Cabinet clock, seconds part. |
| `fri_ns` | ns | `LBRState.time_stamp_nano_sec` | Cabinet clock, nanoseconds part. **Quantised to the 10 ms sample period** — see the clock section below. Together with `fri_s` this is the exact, jitter-free sample grid and the anchor for NSP alignment. |

#### End-effector pose (all experiments)

Forward kinematics of `measured_joint_position`, expressed in `lbr_link_0` (the robot base).
Computed by the recorder rather than read from TF, so pose and joints share one timestamp.

| Column | Unit | Meaning |
|---|---|---|
| `x` `y` `z` | m | EE position in the base frame. |
| `qx` `qy` `qz` `qw` | — | EE orientation as a unit quaternion (scalar last). The apple can be pulled off-axis, so orientation is measured, not assumed. |

#### Joints (all experiments)

Seven values each, `A1`…`A7`, base to wrist. **Radians and newton-metres — SI throughout.**
(`record_fri_session.py` writes degrees; the two files are deliberately not the same convention.)

| Column | Unit | Source | Meaning |
|---|---|---|---|
| `meas_A1..A7` | rad | `measured_joint_position` | Where the arm actually is. |
| `cmd_A1..A7` | rad | `commanded_joint_position` | Where the cabinet is commanding it to be — under Cartesian impedance this is the *equilibrium*, not a position the arm will reach. |
| `ext_A1..A7` | Nm | `external_torque` | Torque the cabinet attributes to outside forces, gravity model removed. This is how a pull is measured without a force sensor. A steady non-zero value at rest means un-modelled tool mass. |

**`cmd − meas` is the impedance droop.** Under Cartesian impedance the arm deliberately lags its
equilibrium by `F / k`; that difference is the signal, not an error.

#### FRI health (all experiments)

Mostly constant. Included per-sample so a bad trial is self-diagnosing without cross-referencing a
second file.

| Column | Source | Values |
|---|---|---|
| `tracking` | `tracking_performance` | 0…1. How well the cabinet is following the command; drops when the commanded pose is unreachable or the arm is being fought. |
| `session` | `session_state` | 0 IDLE · 1 MONITORING_WAIT · 2 MONITORING_READY · 3 COMMANDING_WAIT · **4 COMMANDING_ACTIVE** (the only one in which commands take effect) |
| `quality` | `connection_quality` | 0 POOR · 1 FAIR · 2 GOOD · 3 EXCELLENT |
| `safety` | `safety_state` | **0 NORMAL_OPERATION** · 1 SAFETY_STOP_LEVEL_0 · 2 LEVEL_1 · 3 LEVEL_2 |
| `drive` | `drive_state` | 0 OFF · 1 TRANSITIONING · **2 ACTIVE** |
| `control` | `control_mode` | 0 POSITION · **1 CART_IMP** · 2 JOINT_IMP · 3 NO_CONTROL |

Anything other than session 4 / safety 0 / drive 2 for any part of a trial means that trial is
suspect, and `validate_recording.py` fails it.

#### Events (all experiments)

| Column | Meaning |
|---|---|
| `event` | Empty on most rows. On the first sample at or after an event, the token from the event tables above. Several events can land on one sample; they share the cell, joined with `|`. |
| `event_arg` | One number whose meaning depends on the token: trial index, displacement in m at `snap`, checkpoint index, perturbation magnitude, safety reason code. Empty where the token carries no payload. |

Events land on a **sample boundary**, so their time is known to ±5 ms from the row alone. Recover
finer timing by interpolating the underlying signal — see the clock section below.

#### Apple pluck / perturb only

| Column | Unit | Source | Meaning |
|---|---|---|---|
| `disp_m` | m | `CartesianImpedanceDisplacementMonitor` | Distance of the EE from the baseline pose locked at `armed`, along `cartesian_axis` (`norm` = 3-D distance). **`nan` when the monitor is not measuring**: before `armed`, and from the end of the post-snap hold onward. **The dependent variable.** The trial ends when it crosses `cartesian_displacement_threshold_m`. Recording it per sample is what makes the crossing time recoverable to sub-millisecond by interpolation. |

#### Maze only

All maze coordinates are **relative to the anchor** — the EE pose captured after the fixture's
`anchor_settle_sec` — and lie in the plane left free by `restricted_axis` (the maze is in Y-Z, so
`a` = Y and `b` = Z).

| Column | Unit | Meaning |
|---|---|---|
| `rel_a` | m | In-plane offset from the anchor along the first free axis. |
| `rel_b` | m | Same, second free axis. Plot `rel_b` against `rel_a` to get the maze view. |
| `corridor` | index | Index of the nearest corridor **when on-rail**, else **−1**. Not a strict inside/outside test: the corridors are zero-width lines, so "on rail" means within `on_rail_tol` of one. |
| `off_rail` | 0 / 1 | 1 when the arm is further than `on_rail_tol` from every corridor — i.e. being actively pulled back by the virtual fixture. Mirrors `corridor == -1`. |
| `rail_dist` | m | Distance to the **nearest** corridor segment, always populated. On-rail it is ≤ `on_rail_tol`; off-rail it is how hard the fixture is working. |

`rail_nearest` is the index of the nearest corridor, **always populated** — on-rail or not. Off-rail,
`corridor` reads −1, and `rail_nearest` says *which* corridor the arm has been pushed off.

#### Sidecar fields

| Field | Meaning |
|---|---|
| `schema_version` | Bump when columns change, so loaders can branch. |
| `experiment` | `apple_pluck` · `perturb` · `maze` |
| `trial_index` | Counter within the session. |
| `session_id` | Shared by every trial from one launch. |
| `subject` | Animal identifier, from a ROS param. |
| `clock_sync.start/end` | All four clocks sampled together at both ends of the trial. Gives the offsets *and* the drift over that trial. |
| `fri` | `sample_time_s`, and the session/control mode at trial start. |
| `controllers_active` | Which ros2_control controllers were running — catches "wrong controller was loaded". |
| `git` | Commit SHA and dirty flag of the stack that produced the file. |
| `start_pose` | Commanded and measured joint vectors at trial start. |
| `baseline` | Apple pluck / perturb: the pose `disp_m` is measured from. |
| `perturbation` | Perturb: the applied offset vector. Constant per trial, hence metadata not a column. |
| `maze_geometry` | Maze: corridors, checkpoints and goal **as they were at record time**. Without this an old run silently plots against whatever `maze_params.yaml` says today. |
| `params` | Full resolved ROS parameter dump for the orchestrator node, taken when the trial starts, so it includes any live change applied at that trial (dashboard or `ros2 param set`) and a dashboard run's per-run edits. |
| `events` | **Every `mark()` with the moment it actually happened** — `t`, `t_wall`, `t_ros`, `fri_s`, `fri_ns` and the CSV row it landed on. The CSV column is quantised to the 10 ms sample grid; this is not. Use the column to *find* an event, this to *time* it — and it is what a TTL pulse lines up against. |

### Sizing

```
47 columns × ~12 B × 100 Hz  ≈  55 KB/s  ≈  3.3 MB/min
```

A 10-minute maze run is ~33 MB. Rows are written **incrementally** and flushed on every event row,
and the sidecar is rewritten on every event — so a crash or Ctrl-C costs at most the last fraction
of a second, and the interrupted trial is marked `partial: true` rather than looking complete.

Recorded data is gitignored ([Where files go](#where-files-go)).
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

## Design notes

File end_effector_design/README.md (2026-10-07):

# Apple-Pluck End-Effector (parametric)

A 3D-printable tool that bolts to the **KUKA LBR iiwa7 media flange (electric)** and presents a
compliant **"apple"** for the monkey to pull. It is also an **electronics hub**: it routes the
media-flange power/data, drives a **NeoPixel ring** visual cue, and carries the control board, the
DC-DC converter, and small breakouts, with wiring extending to an **ERM/LRA actuator** and a
**pressure sensor** in the apple. Authored in **OpenSCAD** so it's text-based, parametric, and
version-controlled. `check_layout.py` verifies the geometry against the `.scad`; run it after any
size change.

## Design at a glance
The tool is a stack of four printed discs — flange plate, two base tiers, cover — with the apple on
top and a clear casing box over the lot:

```
[ iiwa7 media flange (electric) ]   8× M6 on Ø51 (pitch circle) · Ø34 electric bore · 24 V + data bundle
  (0) FLANGE PLATE    Ø124 × 16. Takes the 8× M6 — heads + washers BURIED so its top face is flat —
                      plus the Ø30 cable bore. Tier 1 bolts onto IT with 6× M3 on a Ø100 circle
                      (first at 15°). Bolt the plate to the robot BARE, then drop the base on: the
                      printed base never carries the M6 clamp load, and you never reach past boards
                      to a flange bolt.
        │  cable bundle up the Ø30 centre
  (1a) BASE TIER 1    Ø188 × 33 (14 mm floor + 19 mm compartment). Ø30 central bore — the flange
                      bundle lands HERE. ONE open compartment, r 19 → 88, flat floor. Standing in it:
                      4× Ø12 screw pillars on a SYMMETRIC Ø150 bolt circle (45/135/225/315).
                      Sunk INTO the floor (so wiring runs UNDER the boards):
        ├─ 2 PERIMETER TRENCHES  r 66→86, 6 deep, 74° each (PEG TO PEG) centred at 0° and 180° =
        │   98 mm of run apiece (196 total), 3 cable-tie slots each. Split the bundle, one half per side.
        ├─ 2 FEED CHANNELS  10 wide, at 30°/210° — one diagonal line through the bore, each meeting
        │   its trench at an END so the bundle runs the trench's full length
        ├─ 4× Ø10 RADIAL BORE PORTS  at 30/120/210/300, bottoms flush with the floor. The two at
        │   30/210 sit ON the feed channels and are squared down to the channel floor, so bore,
        │   port and channel are ONE continuous opening with no web to climb
        ├─ the rest of the floor is FLAT
        └─ reference boards (velcro anywhere): Metro M4 AirLift 92 × 50 · RS-422 click 45 × 28 ·
           MPRLS pressure 20 × 19
  (1b) BASE TIER 2    Ø188 × 32 (10 mm floor + 22 mm compartment). Stacks on tier 1 with 4× M3×14
                      into tier 1's pillars. Ø20 bore — only ring/apple wiring goes higher, and those
                      5 mm of radius per side are what let the 70 × 65 Tobsun fit inside Ø188 at all.
                      ONE open compartment, r 14 → 88, flat floor (no channels).
        ├─ 4× Ø12 PILLARS on Ø120 (45/135/225/315) carrying the COVER inserts
        ├─ 4× Ø10 RADIAL BORE PORTS at 0/90/180/270 — apple / ring wiring out of the riser
        ├─ 4× Ø10 DROPS through the floor at r 58 (0/90/180/270) — tier-2 → tier-1 wiring
        └─ reference boards: Tobsun 70 × 65 (22 tall — sets the tier depth) · level shifter 36 × 28 ·
           DRV2605L 28 × 20
  (2) COVER           Ø188 × 9. Seats the NeoPixel ring in a Ø165/152 groove on its TOP (LEDs up,
                      opaque cover) · closes tier 2 · 4× M3 down into tier 2 at Ø120 — INSIDE the
                      ring · 4 ring-lead pass-throughs (one per quarter) · 3× M3 pilots on Ø64 for
                      the casing box · Ø44 boss (R4 fillet to the plate) for the apple stem
        ▼  BOLTED FLANGE: apple STEM screws down into the cover boss (3× M3 on Ø36 + Ø24 centring spigot)
  (3a) APPLE STEM     ONE PETG part: Ø44 cover flange + 100 mm shaft TAPERING Ø24 → Ø14 (Ø9 feed bore,
                      R2 root fillet), then a Ø20 SEAT and a Ø12 TIP up through the ball. Apple height is FIXED
                      by stem_shaft_len — reprint to change it. Apple centre sits 212 mm above the flange.
  (3b) TPU BALL       Ø45, printed alone. Flat base sits on the seat; Ø12 hole for the tip; solid floor;
                      OPEN top loads the ERM + force sensor. 45° teardrop neck, so it prints unsupported.
  (3c) RETAINER       small PETG ring (Ø22 × 3 + Ø16 hub), dropped in through the open top and GLUED onto
                      the tip — it clamps the ball's floor down onto the seat.
  (3d) TPU CAP        press-fit dome closes the ball; wires / FSR tail / pressure tube exit the bore
  ( + ) CLEAR CASING BOX  198 × 198, 5-sided (open on the flange side), over the whole stack; its top
                      clamps with 3× M3 into the cover on Ø64
```

> **Joints.** The cover↔stem joint is a **bolted flange** (Ø44, 3× M3 on a Ø36 bolt circle, centred by
> a Ø24 spigot, cable bore down the middle). The flange sits at the centre of the big ring (ID Ø145), with
> plenty of clear space between the apple mount and the ring.
>
> **Fixed height.** The flange, tapered shaft, seat and tip are **one PETG part** (`apple_stem`). One piece has no radial slop to rock on; height is set by
> **`stem_shaft_len` (100 mm)** — change it and reprint.
>
> **The apple prints as four single-material parts:** stem (PETG), ball and
> cap (TPU), retainer (PETG). The ball slides down the tip onto the stem's **seat**; the **retainer**
> drops in through the open top and is **glued onto the tip** — PETG to PETG, a strong bond — clamping the
> ball's solid floor between retainer and seat. **Pulled, the floor bears on the retainer; pushed, the
> base bears on the seat.** No load rides on a TPU bond (TPU barely bonds to anything). Then load the
> ERM + force sensor through the open top, route their wires / FSR tail / pressure tube down the **Ø9
> bore**, and press the cap on.

## Power / data flow
```
24 V (cabinet, via X650/X651) ─► Tobsun 24 V→5 V ─► 5 V ─┬─► Metro M4 AirLift board
                                                 ├─► NeoPixel ring   (via Pixel Shifter: 3.3 V data → 5 V)
                                                 ├─► DRV2605L driver ─► ERM/LRA motor (actuator, apple cavity)
                                                 └─► pressure sensor (apple cavity)
   data: Metro 3.3 V ─► Pixel Shifter ─► ring DIN ;  Metro I²C ─► DRV2605L ;  sensor ─► Metro ADC/I²C
```
> **Ring current.** The 60-LED RGBW ring can pull **~3.5 A at 5 V** at full-white — inject 5 V at each
> of the 4 quarter pass-throughs (don't feed 60 LEDs through one arc). Size the converter for it, and
> keep brightness capped in firmware and size the 5 V wiring for the load.

The **Metro M4 Express AirLift** runs everything: it drives the NeoPixel ring through the **Pixel
Shifter** (its 3.3 V data needs shifting to 5 V), commands the **DRV2605L** over I²C to run the
haptic **actuator** (an ERM/LRA motor in the apple), and reads the **pressure sensor**. The
**Tobsun converter** steps the 24 V down to 5 V; that **5 V rail is distributed from it** out
to every board and up the centre riser (ring + apple). All the boards live in the base; only the
ERM motor + pressure sensor sit up in the apple cavity.

## The media flange is a pass-through — the as-built wiring

This robot has the **Media flange Inside electric**: two supply voltages, two analog/CAT5
interfaces, an internal connector, and **no electronics of its own** (KUKA media-flange manual V10,
20 Oct 2021, §2.1.9). It is a conduit from interface A1 at the rear of the base frame (Fig. 5-1) to
the tool connector at the wrist.

**On this arm:**

```
   [ robot base, interface A1, rear of base frame ]

     X31  ══ robot data cable ══► Sunrise cabinet          connected
     X651 ══ KUKA data cable X650/X651 ══► cabinet         connected
          └─ carries 24 V + GND (pins 5/6) and EtherCAT (pins 9-12), Fig. 5-63
                                     │
     X76  ── your trigger wiring ────┤                     12+3 bypack fitted
                                     ▼
   [ tool connector at the flange face ]   16-way breakout, ~44 cm
```

Three consequences that shape the whole design:

1. **The 24 V is already there, from the cabinet.** The X650/X651 data cable puts 24 V on X651
   pin 5 and GND on pin 6, which the flange passes to **tool connector pins 1/2**. The Metro board
   and the ring both run from it; no external PSU is needed. (KUKA's parts list for this flange
   calls for a *connector bypack* on X651 rather than the data cable, so this is an off-book but
   functionally clean configuration — the pin roles line up.)
2. **EtherCAT is live at the wrist**, on tool pins 3-6. Keep those insulated. An EtherCAT slave at
   the tool would give cabinet-native timing and a return channel for sensors — a hardware option
   not pursued at present.
3. **The cabinet cannot drive a cue line through the flange itself.** The manual's list of flanges
   with configurable I/O (§7.1) does not include Inside electric, so no `MediaFlangeIOGroup` is
   generated and Sunrise has no flange output to assert. The trigger is driven by whatever you
   land on **X76**, whose CTR pairs pass to tool pins 9-16.

### Tool connector pinout

The breakout is **12× AWG26 signal + 4× AWG18 power**, arriving as three 2-wire bundles and two
3-wire bundles (each 3-wire group is a shielded pair plus its drain).

| Tool pin | Colour | Signal | Via | Rating / use |
|---|---|---|---|---|
| **1** | RD | **Power1** | X651 5 | 60 V / 8 A — **live 24 V from the cabinet** |
| **2** | BK | **GND1** | X651 6 | |
| 3 | YE | CAT5 TXP | X651 9 | **live EtherCAT — insulate** |
| 4 | OG | CAT5 TXN | X651 11 | **live EtherCAT — insulate** |
| 5 | WH | CAT5 RXP | X651 10 | **live EtherCAT — insulate** |
| 6 | BU | CAT5 RXN | X651 12 | **live EtherCAT — insulate** |
| 7 | RD | Power2 | X76 A | 60 V / 5 A — unused; fallback supply if the cabinet 24 V won't carry the ring |
| 8 | BK | GND2 | X76 B | |
| **9** | BK | **CTR1_1** | X76 1 | **cue trigger** (shielded pair) |
| **10** | BU | **CTR1_2** | X76 2 | |
| 11 | WH | CTR1_3 | X76 3 | drain — bond at ONE end only |
| 12 | GN | CTR2_4 | X76 4 | spare pair — haptic trigger |
| 13 | YE | CTR2_5 | X76 5 | |
| 14 | WH | CTR2_6 | X76 6 | drain |
| 15 | RD | CTR3_7 | X76 7 | spare pair — **reserve for the force sensor** |
| 16 | BU | CTR3_8 | X76 8 | |

> **Colour is ambiguous — meter it.** WH, BU and RD each appear three times. The bundle grouping
> disambiguates, but map the breakout to X651/X76 with a continuity test before landing anything.
> The manual is also internally inconsistent here: the connection table says "6× AWG28" on X76
> while the wiring diagram (Fig. 5-39) labels eight CTR conductors. The meter settles it.

> **Why convert locally rather than feed 5 V down Power1?** Voltage drop. AWG18
> over the robot's internal harness plus the 44 cm breakout drops roughly 0.5 V at the ring's worst
> case — and the drop *varies with how much of the ring is lit*, so cue colour would shift with cue
> settings. Converting at the tool keeps the ring on a stiff 5 V, and the 24 V feed carries ~1.25 A
> instead of ~4.8 A for the same power. Measure the real round-trip resistance (short Power1 to
> GND1 at the tool, measure across X651 5–6) before revisiting this.

### Commissioning the trigger — do it in this order

Each step proves one thing and has a stop condition. Do not skip ahead.

**0. Prep — arm de-energised.** Mount the tool connector **flush** (4× M2×16, 0.35 N·m; if it is
not flush, contact is not guaranteed and every later step will lie to you). Individually insulate
all 16 breakout wires; uninsulate only what each step needs. **Pins 3–6 stay capped permanently —
live EtherCAT.** X651 remains plugged into the cabinet, so pins 1/2 and 3–6 may be live whenever the
cabinet has power.

**1. Crimp X76.** Contacts **1**, **2**, **3**, and **9** (screen). Leave A/B/C and 4–8 empty.
Do not terminate the far end yet — it depends on step 4.

**2. Ring it out — arm de-energised.** Two measurements, because one is not enough:

| At the base | At the tool | Proves |
|---|---|---|
| short X76 **1 ↔ 2** | continuity **pin 9 ↔ pin 10** | both conductors are through |
| short X76 **1 ↔ 3** | continuity **pin 9 ↔ pin 11** | contact 1 really is pin 9, i.e. **no swap** |

The first test passes identically whether or not 1 and 2 are swapped; only the second catches it.
A swap does not matter for a bare contact closure but is fatal for a polarised receiver.
While you are here, short tool 9 to tool 10 and measure across X76 1–2 for the **round-trip
resistance** — every voltage-drop estimate depends on that number.

**3. Passive jumper test — no source, no voltage.** Wire tool pin 9 → Metro **D2** and tool pin 10 →
Metro **GND**. The firmware's `active_low` default plus D2's internal pull-up means a bare short is a
valid trigger.

```bash
ros2 run sinthlab_bringup check_cue_wiring.py          # or: python3 diagnostics/check_cue_wiring.py
```

It pre-flights the board (catches `enabled=0`, an invisible cue, and **inverted polarity**), then
announces every edge as you make and break the short at X76. This step verifies
`CUE_PIN = board.D2` against real hardware.

> **Stop condition:** no edges means wiring, not firmware. The tool prints the likely causes ranked.

**4. Fit the RS‑422 link (parts on order).** The cabinet cannot drive the trigger — the Sunrise
project has no generated I/O groups — so the ROS computer drives it, over a **full‑duplex RS‑422
serial link**. The same link carries the pressure sensor's data off the tool:

| | Part |
|---|---|
| ROS box | StarTech **ICUSB422IS** — isolated USB↔RS‑422, FTDI FT232RL |
| Tool | MikroE **MIKROE‑2821** RS485 3 Click — SN65HVD31, full duplex, 3.3 V |

The MikroE's screw terminals take the CTR pairs from the tool connector; its header pins go to the
Metro's UART (3.3V, GND, TX/D1, RX/D0 — **check D0/D1 are free** on the AirLift Lite before wiring).
It's a **crossover**: the adapter's TX pair lands on the MikroE's RX pair and vice versa. Put the
differential signals on the **shielded** CTR pairs. Set the FTDI `latency_timer` to 1 on the ROS box,
or you get 16 ms of buffering. Full detail in
[§6.7 of the top-level README](../README.md#67-end-effector-board--the-visual-cue).

The jumper test in step 3 is the first check of the harness either way — it proves continuity
before any electronics are involved.

### Handling limits from the manual

- **Tool connector: max 100 mating cycles.** Do not prototype by repeatedly unplugging it.
- Connect/disconnect **de-energised only**, and insulate every unused cable end — a loose end shorts
  and damages the flange.
- The connector must sit **flush** with the flange face or contact is not guaranteed.
  4× **M2×16**, torque **0.35 N·m** (class 8.8) per §12.1.
- Minimum breakout bending radius **5.85 mm**; strain-relieve on the tool side.
- IP54 requires sealing between flange and tool. Flange (230 g) and tool-connector weights are
  accounted for automatically by Sunrise.
- **Stopping distances:** the manual's tables (§4.16.3, §4.16.5) list which flanges they cover, and
  plain *Inside electric* is in neither — only the NE and NE II variants are. It is 230 g with the
  same payload table as the Basic-flange, so those figures very probably apply, but confirm with
  KUKA before relying on them in a risk assessment.

## Components (dimensions locked from datasheets)
| Item | Part / link | Size (mm) | Drives parameter |
|---|---|---|---|
| NeoPixel ring, 60×5050 RGBW (**buy 4× quarter-rings**) | [Adafruit 2874](https://www.adafruit.com/product/2874) | PCB Ø157 / Ø145 × 3.25 (6.2″) — **groove is cut Ø165 / Ø152** | `ring_pcb_od/id`, `ring_od`, `ring_id`, `ring_groove_h` |
| Control board (+ its power adapter) | [Metro M4 Express AirLift Lite (4000)](https://www.adafruit.com/product/4000) | **92 × 50** | `board_l/w`, `board_pos` |
| DC-DC converter | **Tobsun 24 V→5 V** | **70 × 65** | `conv_l/w`, `conv_pos` |
| NeoPixel level shifter | [Pixel Shifter (6066)](https://www.adafruit.com/product/6066) (3.3→5 V data) | **36 × 28** | `shifter_*` |
| Actuator driver | [DRV2605L (2305)](https://www.adafruit.com/product/2305) (ERM/LRA driver, I²C) | **28 × 20** | `haptic_*` |
| **RS-422 transceiver** | [MIKROE-2821 RS485 3 Click](https://www.mikroe.com/rs485-3-click) — SN65HVD31, full duplex, 3.3 V | **42.9 × 25.4** (footprint 45 × 28) | `rs422_l/w`, `rs422_pos` |
| Haptic actuator | [Vibrating Mini Motor Disc (1201)](https://www.adafruit.com/product/1201) (coin ERM) | **Ø10 × 2.7** | apple cavity |
| Force sensor **A** | [FSR — Alpha MF01A round, high-force 1–98 N (5475)](https://www.adafruit.com/product/5475) | **Ø18 head** (~Ø15 active) · 60 long · 0.56 thin | apple cavity (head) + tail down bore |
| Force sensor **B** | [MPRLS ported pressure sensor (3965)](https://www.adafruit.com/product/3965), I²C 0–25 PSI | board **17.8 × 16.7 × 7.5** (footprint 20 × 19) · port Ø2.5 | `mprls_*` on **tier 1** + Ø2–3 tube up the riser to a *sealed* cavity |

> **Fit notes (read before printing):**
> 1. **Base is Ø188, and the RING is why — not a board.** The groove outer sits at r = 83.5; add solid
>    rim and a wall and you arrive at r = 94. Run **`python3 check_layout.py`** after *any* size change:
>    the tightest fit is the Tobsun at **1.6 mm** of margin (corner r 86.4 against 88), and the script
>    checks every board, screw, port, drop and trench.
> 2. **Two tiers, and the bore sizes are load-bearing decisions.** Tier 1 has the Ø30 bore because the
>    flange bundle lands there. Tier 2 has Ø20 because only ring/apple wiring goes higher — and those
>    5 mm of radius per side are exactly what lets the 70 × 65 Tobsun fit. At Ø30 its corners land at
>    **r = 90.1** and it does **not** fit inside Ø188 in any orientation. Any growth in `hub_wall`,
>    `conv_l/w` or `tier2_bore_d` means the base grows or the Tobsun and Metro swap tiers.
> 3. **The layout is Cartesian, not polar.** Large rectangles reaching in toward the bore cannot be
>    placed on a bolt circle: at the hub their angular widths exceed 360°. Each board has an explicit
>    `*_pos` = [x, y] and `*_rot`.
> 4. **Every screw lands on a pillar.** Each compartment is open, so there is no solid top face for a
>    heat-set insert; each tier carries **4× Ø12 pillars** from its floor to its top — tier 1's on
>    Ø150 at 45/135/225/315 (taking the tier-2 screws), tier 2's on Ø120 at the same angles (taking the
>    cover screws). Both are **symmetric bolt circles**, so the clamp load is centred. They are the
>    only obstructions in either compartment; the checker holds every reference board clear of them,
>    verifies even spacing, confirms they sit between the trenches and clear of the channels, and
>    that the tier-2 pillars (to r 66) clear the tier-1 screw counterbores (from r 71.75).
> 5. **Cover screws are INSIDE the ring (Ø120).** Outboard is not possible: the gap between the
>    groove outer (r 83.5) and the rim inner (r 91) is 7.5 mm, and an M3 counterbore is 6.5 wide. At
>    r = 60 the counterbore ends at 63.25, clear of the groove at 75.
> 6. **The ring groove is deliberately oversized.** The channel is **8.5 mm wide against the ring's
>    6 mm**, so the arcs can sit anywhere from hard against the inner wall (r 72.5–78.5) out to hard
>    against the outer (r 77.5–83.5). Sitting further out is what buys the circumference: at r 79 the
>    60 LEDs need **496 mm** of arc against **474 mm** at r 75.5 — about three LEDs, enough to stop four
>    butted quarter-arcs closing. **Seat the segments pushed outward.**
> 7. **No pockets and no board screws.** Each tier is ONE open compartment (r 19 → 88 on tier 1,
>    r 14 → 88 on tier 2) with a flat floor; every board is **velcro'd** wherever it fits. The board
>    dimensions in the .scad are a *reference placement* that `check_layout.py` validates and
>    `electronics_mock` draws — they do not shape the print, so you can move or swap a board on the
>    bench without reprinting anything. Each `*_clear` is the height that board needs, and the tallest
>    on each tier sets the compartment depth: Metro 19 → `comp1_depth`, Tobsun 22 → `comp2_depth`.
> 8. **Every wire has a hole to get through.** Each bore is a 4 mm tube the full height of its tier:
>    - **4× Ø10 radial ports** in tier 1's bore wall and **4× Ø10** in tier 2's, all with their bottoms
>      flush to the compartment floor so wire leaves lying flat rather than climbing over the hub.
>    - On tier 1 two of the four are **clocked onto the feed channels** (`hub_port_a0 == radial_a0`,
>      enforced by the checker), so bore, port and channel form one continuous opening out to the
>      trench, 10 mm wide from the channel floor up.
>    - **4× Ø10 drops** through tier 2's floor at r 58 (0/90/180/270, between the pillars) for
>      tier-2 → tier-1 wiring. The reference Tobsun placement sits over the drop at 90°; the other
>      three are clear, or slide the Tobsun.
>
>    The ports take a large share of each hub's circumference, and the hub is also part of the face
>    the tier above lands on; `check_layout.py` caps it. Drop `t2_port_d` to 8 if tier 2's hub prints
>    badly.
> 9. **Cable management runs UNDER the boards, and splits the bundle in two.** Tier 1 has **two
>    perimeter trenches** (r 66→86, 74° each, centred at 0° and 180°, **98 mm of run apiece**, 3 tie
>    slots each), each fed by its **own 10 mm channel** from the central bore. The channels sit at
>    30°/210° — a single diagonal through the bore — and each meets its trench at an **END**, so the
>    bundle enters at one end and runs the full length. Split the bundle in half at the bore and dress
>    one half into each side; each trench fills the gap between two screw pillars (4.4 mm of wall to
>    the nearest pillar), so nothing has to get past a pillar. All of it is **sunk 6 mm below the
>    compartment floor**, so a board velcros straight over a cable run, with 8 mm of solid floor left
>    underneath. **Tier 2 has no channels** — nothing there needs routing under a board.
> 10. **Assembly order is forced: plate → robot → tier 1 → boards → tier 2 → boards → cover.** The 8 M6
>    live in the **separate flange plate**, driven with the plate bare. Tier 1 then bolts down with
>    **6× M3×14 on the Ø100 circle (first at 15°)**, their heads recessed into the floor. The
>    compartment is open so every head is in plain sight — but they sit **under where boards go**, so
>    drive them before you velcro anything down.
> 11. **Tapered shaft, close apple.** The stem **tapers from Ø24 at the cover flange to Ø14 under the
>    ball** (`stem_base_d` → `stem_shaft_d`), with a **Ø9 feed bore** and an R2 root fillet. The base is
>    as wide as it can be: base + fillet reach r 14, just inside the joint screws' counterbores (r 14.75),
>    which need straight-down access for the key. It sits at the very centre, far inside the ring (ID r ≈ 75), so it doesn't occlude the
>    LEDs. Height is **fixed** at `stem_shaft_len = 100` (apple centre 212 mm above the robot flange).
> 12. **Shaft strength and stiffness.** The pull's bending moment is largest at the root, which is
>    why the shaft is thickest there: Ø24 is **8.6× stiffer** than a straight Ø14 (stiffness goes with
>    Ø⁴), so the apple wobbles far less. A 20 N pull at the ball now peaks at about **2.4 MPa** of
>    bending stress, near the top of the shaft (Ø15.5), against ~30–50 MPa for PETG — a safety factor
>    above **10** (a straight Ø14 shaft reached 10 MPa at the root). Print the **stem solid /
>    high-perimeter**. The ball is held by the **Ø22 retainer** bearing on its solid TPU
>    floor, not by any bond to the TPU.
> 13. **Apple cavity + access.** The cavity (dome ≈ **Ø39 × 31 mm** above the flange) fits the **ERM
>    (Ø10)**, the **FSR head (Ø18)**, or the **MPRLS board (17.8 mm)** with room to spare — but all are
>    bigger than the Ø9 bore, so you load them through the **open top** and close the **press-fit cap**
>    (`cap_*`); only wires / the FSR tail / a Ø2–3 mm pressure tube run down the bore. **MPRLS route:**
>    keep the board in the base and run a tube to the cavity — the cavity is the pressure chamber, so
>    **seal it airtight** (raw FDM TPU is porous: coat the inside or drop in a small bladder). Adhere
>    the ERM to the **inner TPU wall** so its buzz reaches the grip.

## Strength — the pull path

A pull at the apple travels **apple → stem → cover → tier 2 → tier 1 → flange plate → robot**. A 20 N
pull is about **4.2 N·m** of moment, and all of it passes through every one of those joints. What
differs is the bolt circle each joint reacts it on:

| Joint | Bolt circle | Force per screw (tension side) |
|---|---|---|
| **apple stem → cover** | **Ø36** | **78 N** |
| cover → tier 2 | Ø120 | 18 N |
| tier 2 → tier 1 | Ø150 | 14 N |
| tier 1 → flange plate | Ø100 | 14 N |

**The most-loaded joint in the tool is the apple stem to the cover** — the same moment reacted across
a third of the diameter. So the cover is structural:

- `cover_plate_t` is **9 mm**: bending just outside the Ø44 boss is ~7 MPa (**SF ≈ 7** on bulk PETG,
  nearer 4–5 once flat-print layer strength is allowed for);
- **4.5 mm** of material under the ring groove and **4 mm** under each casing insert;
- an **R4 fillet** where the boss meets the plate, instead of a sharp step.

**At the base↔flange joint** the screws carry only ~14 N each; what matters is the printed material
around them:

- **10 mm of floor under each M3 head** (hence **M3×14** there: 10 through the floor + the full 4 mm insert), and 8 mm where a cable channel
  crosses;
- a **14 mm** tier-1 floor;
- a **Ø124** plate, which supports tier 1's floor so it overhangs by only 32 mm;
- a **Ø100** bolt circle — wider circle, lower force per screw;
- a **4 mm** hub wall around the bore ports;
- **R3 fillets** at every compartment-wall and pillar-base corner. A flat-printed disc cracks
  along its layers, and sharp internal corners are where that starts.

Tier 2 carries the same moment but on a 10 mm floor spanning only 15 mm from pillar to tier screw,
which works out at **SF ≈ 24**. It does not need the full structural profile — but it is in the
load path, so do not go below its print settings.

**Geometry is only half of this — see [Print settings](#print-settings).** The discs print flat, so
the moment at each bolt circle pulls directly against the layer bonds, the weakest axis by a wide
margin.

## Fasteners — order list (BOM)
The whole tool uses **two thread sizes** — **M6** (robot flange only) and **M3** (everything else) —
plus **one insert size** (M3 heat-set). Screw heads can be **cap (hex/Allen) or cheese (screwdriver)** —
both share the Ø5.5/Ø10 head, so the counterbores fit either. The build here uses **cap-head M3** (Allen).

| Fastener | Spec | Qty | Where / notes |
|---|---|-----|---|
| M6 cap-head screw | **M6 × 16** | 8 | **Flange plate** → into the robot flange's **own tapped holes** (Ø51 pitch circle; Ø7.0 clearance holes). Head sits on a **steel M6 washer** in the Ø14 seat, buried flush in the 16 mm plate. Spans the 8 mm wall + washer → **~6.4 mm thread bite**; **verify the flange tap ≥ 7 mm** (or use M6×18 for ~8 mm). |
| M3 cap-head screw | **M3 × 14** | 14 | **One length for the base and cover joints.** Each engages its whole 4 mm insert and stops short of the hole bottom: **tier 1 → flange plate** (6×, Ø100: 10 mm of floor under the head — the critical section of the base joint — + 4 into the 6 mm plate hole, 2 mm spare); **tier 2 → tier 1** (4×, Ø150: 5 + 9 into the 14 mm pillar hole); **cover → tier 2** (4×, Ø120: 6 of the 9 mm cover + 8 into the 14 mm hole). **Not M3 × 16** at the plate: it needs the whole 6 mm hole, so it bottoms out before the head clamps and leaves a gap. |
| M3 cap-head screw | **M3 × 10** | 3 | **Apple stem → cover boss** (Ø36): 5 mm of the stem flange under the head + 5 mm into the boss (7 mm bore). **Not longer** — an M3 × 12 or longer bottoms out in the 7 mm hole and lifts the stem off the cover. |
| M3 cap-head screw | **M3 × 6** | 3 | Casing-box top → cover (Ø64). **Short on purpose** — the cover pilot is only 5 mm deep, so M3×10 would bottom out and never clamp. |
| M3 brass heat-set insert | **Bambu M3×5×4** (M3, 5.0 mm OD, 4 mm long) | 20 | 6× **flange plate** + 4× **tier-1 pillars** (tier 2) + 4× tier-2 pillars (cover) + 3× cover boss (stem) + 3× cover top (casing). Printed hole is **Ø4.6 (`m3_insert`)**; the 4 mm length seats in every pilot (shallowest = 5 mm cover top). |
| Steel washer, M6 | flat, OD ~12 (DIN 125) | 8 | **Under each M6 head** in the plate — spreads bolt torque so the printed 8 mm wall can't crush. Seats in the Ø14 recess (`flange_washer_*`). |
| Washer, M3 | small | 3 | Under the casing-top screws — spread the clamp load on the clear sheet. |
| **Hook-and-loop (velcro) pads** | ~2 mm thick | 6 boards | **Every board is stuck down, not screwed.** Board heights already allow for the pad (`velcro_t`). |

> **Shopping summary:** **M3 cap-head** — M3×14 (×14), M3×10 (×3), M3×6 (×3); **M6×16** (×8) +
> **8 steel M6 washers**; **M3 heat-set inserts** (**Bambu M3×5×4**, ×20); **3 M3 washers** (casing)
> + **velcro** for the six boards. **Every screw-into-plastic joint takes the same M3 insert; there is
> no self-tapping and there are no board screws.**

## Files
| File | What |
|---|---|
| `apple_pluck_end_effector.scad` | the parametric model (flange plate, both base tiers, cover, apple stem, ball, cap, casing, assembly) |
| `check_layout.py` | verifies board fit, pillars, ports, drops, trenches, screw clearances and the strength section against the `.scad` |
| `README.md` | this file |

## Render / export
Open `apple_pluck_end_effector.scad` in the **OpenSCAD GUI** (Customizer exposes every parameter), or
export each printed part headless:

```bash
openscad -D 'part="flange_plate"'    -o flange_plate.stl    apple_pluck_end_effector.scad   # bolts to the robot
openscad -D 'part="base_tier1"'      -o base_tier1.stl      apple_pluck_end_effector.scad   # lower tier + cable trenches
openscad -D 'part="base_tier2"'      -o base_tier2.stl      apple_pluck_end_effector.scad   # upper tier
openscad -D 'part="cover"'           -o cover.stl           apple_pluck_end_effector.scad
# APPLE — four single-material prints:
openscad -D 'part="apple_stem"'      -o apple_stem.stl      apple_pluck_end_effector.scad   # PETG (flange + shaft + seat + tip)
openscad -D 'part="apple_ball"'      -o apple_ball.stl      apple_pluck_end_effector.scad   # TPU  (lower ball)
openscad -D 'part="apple_retainer"'  -o apple_retainer.stl  apple_pluck_end_effector.scad   # PETG (glued onto the tip)
openscad -D 'part="apple_cap"'       -o apple_cap.stl       apple_pluck_end_effector.scad   # TPU  (press-fit cap)
# previews only: 'part="assembly"' (default), 'part="apple"' (stem + ball + retainer + cap),
# 'part="apple_section"' / 'part="section"' (half-cuts), 'part="electronics_mock"' (board/ring fit),
# 'part="casing"' (clear casing box — reference only; you build it by hand from clear acrylic sheet)
```

> The **apple_ball** has a sphere, so on the CGAL backend (OpenSCAD 2021.x) F6/STL render is slow
> (minutes); the **Manifold** backend (2023.06+, *Preferences → Features → Manifold*) renders it in
> seconds. Use F5 preview / `part="apple_section"` to check geometry without the wait.

## ⚠️ Verify before printing
- **Flange interface (`flange_*`) — the pitch circle is Ø51, and that is the ONLY number that must match
  the robot.** Measure it **centre-to-centre** across two diametrically opposite holes. Do **not** set it
  from an outer-edge span: that span is `pcd + hole Ø`, and the plate's hole is deliberately *bigger* than
  the flange's tapped hole, so the two spans are not comparable. **Measuring the plate from the top gives
  ~63 mm — that is the Ø12.5 cap-head well, not the bolt hole**; it sits 10 mm above the mating face
  and never touches the robot.

  | where you measure | feature | Ø | centre-to-centre | outer-edge span |
  |---|---|---|---|---|
  | the **robot flange** | tapped M6 hole | 6 | **51** | 57 |
  | plate, **mating face** (z=0) | M6 clearance hole | **7.0** | **51** | 58 |
  | plate, washer recess (z=8) | washer seat | 14 | 51 | 65 |
  | plate, **top face** (z=16) | M6 head well | **12.5** | 51 | **63.5** |

  The clearance hole is **Ø7.0 (ISO 273 coarse)** on purpose: it absorbs the ±0.5 mm uncertainty in the
  measured pitch circle *and* the fact that FDM holes print 0.2–0.4 mm undersize (a Ø6.6 hole prints ~6.3
  and binds on an M6). The Ø12 steel washer under the head covers it easily. Set the pitch circle from
  the flange's **tapped** holes (Ø6), never from the plate's clearance holes.

  Also confirm: the **exact hole clocking** (8 holes evenly at 45°; check `flange_first_angle`), the
  **connector protrusion depth** (drives `flange_center_h` — a 6 mm Ø34 recess in the **plate bottom**),
  and the **M6 tap depth** — the **M6×16** head sits on a steel washer (Ø14 seat) and the shank spans
  `flange_mount_t = 8 mm` + ~1.6 mm washer, leaving **~6.4 mm** of bite, so verify the tap is **≥ 7 mm**
  (use **M6×18** for ~8 mm). **Print the flange plate alone first** — it is small and cheap, and it is the
  only part whose fit to the robot can fail.
- **Bores.** The base's central bore is **Ø30** (`cable_bore_d`) — the media-flange power/data bundle
  comes up through it. Tier 2's is **Ø20** (`tier2_bore_d`). The **cover** and stem have a separate
  **Ø16** bore (`apple_bore_d`) for the apple's own wiring: a Ø30 bore there would swallow the Ø24
  centring spigot.
- **Board fit:** all footprints are locked (see the table). After **any** size change run
  `check_layout.py` — big rectangles around a central bore collide easily. `part="electronics_mock"`
  shows the boards in place.
- **Stem strength:** the shaft is one piece with the flange and tapers from Ø24, so there is no joint to
  test there. Print the stem solid / high-perimeter. **If the apple still wobbles,** check the stem's
  3 screws are **M3 × 10** (longer ones bottom out in the 7 mm holes and never clamp the flange) and
  that the flange sits flat on the cover.
- **Feed bore vs wiring:** `sensor_bore_d = 9 mm` carries the ERM leads, the FSR tail, or a Ø2–3 mm
  pressure tube — the bulky parts load through the press-fit cap, not the bore. Widen it (watch the shaft
  wall) only if your *tail/tube bundle* is fat; tune `cap_lip_clear` for the cap's press-fit, and `tip_clear` / `ret_glue_clear` for the ball and
  retainer on the tip, on test prints.
- **Strain relief:** add a clamp / grommet at the central bore so cable load isn't on the connectors.

## Printing & finishing
- **Flange plate, base tiers, cover:** print flat, face down, in PETG — see
  [Print settings](#print-settings) for the per-part walls, shells and infill.
- **Cover:** opaque, same material as the base; print **top-face up** so the ring groove + screw
  counterbores are open on top (the ring drops in from above). The clear casing box shields it.
- **APPLE STEM (`apple_stem.stl`, PETG):** print it **lying on its side** — the strong axis for a
  100 mm cantilever — with tree supports under the flange and seat; or upright with the layer-adhesion
  settings in [Print settings](#the-apple-stem--lay-it-down). Print it **solid** (load path).
- **APPLE BALL (`apple_ball.stl`, TPU):** prints **upright on its flat base**, no supports (the
  underside is a 45° neck). Low infill keeps it soft and grippable. Keep it **rounded and smooth** — no
  sharp edges or pinch points.
- **RETAINER (`apple_retainer.stl`, PETG):** flat face down, solid. Tiny — put it on the stem's plate.
- **APPLE CAP (`apple_cap.stl`, TPU, separate):** the top dome; print **dome-up** (skirt on the bed). It
  **press-fits** onto the lower ball's rim rebate — tune `cap_lip_clear` on a test print. To hold it
  against pulls, run a thin bead of **neutral-cure silicone (RTV)** round the skirt: flexible, and it peels
  off cleanly when you need inside. Hot glue works too, but a standard gun (~190 °C) can soften the TPU —
  use a low-temperature gun, and know it is harder to undo. Round the seam. Load the ERM + sensor through the open ball,
  route wires / FSR tail / pressure tube down the shaft bore, then fit the cap.
- **Clear casing box:** built by hand from **clear acrylic sheet** (`case_box_*` params) — a 5-sided box
  **198 × 198** outer, walls reaching from the cover top down to the flange plate (~74 mm) plus a
  **3 mm** top, **open on the flange side**. The top has a **Ø44.8** centre hole (clears the apple stem
  boss) and 3 clamp holes on **Ø64**. It clears the Ø188 base by 2 mm a side. Set it over the stack so the
  top covers the ring, then screw the top down with **3× M3 into the cover**. Round all edges near the
  animal. (`part="casing"` exports the box as a dimensional reference; cut/bond it from sheet stock.)

## Assembly (after printing)
Everything is bolted (no glue). **Mount the empty flange plate and tier 1 to the robot first**, then
populate — the boards go in over the screw heads.

> **Two thread sizes only.** **M6×16** at the robot flange (8×, fixed by the flange) and **M3 everywhere
> else**. The single M3 spec lives in `m3_clear / m3_insert / m3_cbore / m3_cbore_h`; every joint derives
> from it. See **Fasteners — order list** above for exact lengths and quantities.

1. **Prepare the threads.** Every screw-into-plastic pilot is modelled at **Ø4.6 (`m3_insert`)** for an
   **M3 heat-set insert (Bambu M3×5×4)** — press one into each: **6× flange plate, 4× tier-1 pillars,
   4× tier-2 pillars, 3× cover boss, 3× cover top = 20**. No board inserts — the boards are velcro'd.
2. **Bolt the flange plate to the robot — bare.** **8× M6×16** through the plate into the flange's tapped
   holes, each on a steel washer in its Ø14 seat; the heads bury flush in the plate's top face. The Ø34
   recess clears the electric connector. Pull the power/data bundle up the **Ø30** bore.
3. **Bolt TIER 1 onto the plate, THEN populate it.** **6× M3×14** down the Ø100 circle into the plate's
   inserts; the heads recess into the floor. **Do this before any board goes in** — those screws sit
   under where boards land. Then dress the tool-connector bundle: bring it up the Ø30 bore, split it,
   and run each half out through its **bore port and feed channel** into a **perimeter trench**; tie it
   down at the slots. All of it sits below the floor line, so boards go on top of it. Now **velcro**
   the Metro, RS-422 and MPRLS down wherever they suit — clear of the four pillars — and land the CTR
   pairs on the RS-422 screw terminals.
4. **Stack TIER 2 and populate it.** Drop tier 2 on and drive **4× M3×14** down at 45/135/225/315 into
   tier 1's pillars (heads recess into tier 2's floor). Pass the 24 V pair up the central riser first.
   Then velcro the **Tobsun, level shifter and DRV2605L** down — anywhere clear of tier 2's four
   pillars — and fan **5 V out from the converter** to every board, back **down through a drop to
   tier 1**, and up to the ring. Leave a service loop at the riser; run the ERM + sensor leads and the
   pressure tube up the centre.
5. **Seat the ring + close the cover.** Butt the **4 quarter-arcs** into the full ring and drop it into
   the cover's **top groove** (LEDs up). The groove is 8.5 mm wide against the ring's 6 mm — **seat the
   arcs pushed OUTWARD, against the outer wall**, which is where the extra circumference is and what
   lets the four segments close. Solder the arc-to-arc joints and feed each arc's power/data leads down
   its **quarter pass-through**. Then lower the cover and drive the **4× M3×14** at **Ø120** (inside the
   ring) down into tier 2's pillars.
6. **Fit the casing box.** Lower the clear box over the stack (open side down to the flange) so its top
   covers the ring, line up the 3 top holes with the **Ø64** pilots, and drive **3× M3×6** (with washers)
   down into the cover. Do this before the apple — the box's Ø44.8 top hole won't pass over an
   assembled apple.
7. **Attach the apple stem, then the ball.** The stem pokes up through the box's top centre hole; set its
   flange on the cover boss (the **spigot** centres it) and drive the **3× M3×10** down into the cover boss.
   Pass the apple wiring up through its bore. Then:
   - **Dry-fit first.** Slide the **ball** down the tip until its flat base sits on the **seat**, and the
     **retainer** onto the tip through the open top: it should sit flat in the floor recess, flush with
     the tip top. Ease a tight fit by sanding, not by forcing the TPU.
   - **Glue the retainer.** Lift it off, put **thin CA (superglue) or 5-minute epoxy** round the top
     ~6 mm of the tip, push the retainer down hard so it clamps the floor, and hold it 30 s. Keep glue
     off the TPU and **out of the Ø9 bore** (run the wiring first, or plug the bore with a wire). Let it
     cure fully (CA: 1 h; epoxy: per the pack) before any pull.
8. **Load the electronics + close the ball.** With the **cap off**, seat the **ERM (Ø10)** against the inner
   TPU wall and the **force sensor** in the open cavity (FSR head against the wall behind a backing; or, for
   the MPRLS route, just the pressure tube — sensor stays in the base). Route the leads / FSR tail / tube
   **down the stem bore**, then **press the cap on** (a bead of silicone if pulls unseat it — see
   [Printing & finishing](#printing--finishing)). Confirm the **cap + ball can't pull off** by hand.
9. **Connect + commission.** Connect the media-flange power/data, **re-calibrate the tool load** in
   Sunrise (electronics + apple add mass — see main repo README §2 "Tool Load Data"), and first
   power-up / move in **T1** with a hand on the E-stop.

Disassembly is the reverse: pull the apple cap → withdraw the apple electronics via the bore → unbolt the
stem (3× M3) → unscrew the casing box → cover → tier 2 (4× M3, boards can stay velcro'd) → tier 1. The only
glue in the stack is the retainer on the stem tip: the ball, retainer and stem come off as one piece
(reprint the stem to change the apple height).

## Print settings

A flat-printed disc under a bending moment fails **along its layer lines**, and every number below is
aimed at that. Every part from the cover down is in the pull path
([Strength](#strength--the-pull-path)).

### The three things that matter most

1. **Dry the filament.** PETG is hygroscopic and wet PETG loses a large fraction of its layer
   adhesion — it prints with a rough, foamy texture and snaps cleanly between layers. Dry at 65 °C
   for 6–8 h and print from a dry box.
2. **Solid layers beat infill.** A plate in bending works like an I-beam: the top and bottom solid
   skins carry almost all the stress and the infill mostly just holds them apart. Adding top/bottom
   layers buys far more than adding infill.
3. **Run hot, cool little.** Layer adhesion rises with nozzle temperature and falls with part
   cooling. For the load-bearing parts go to the top of the PETG range and keep the fan low.

### Per part

| Part | Material | Layer | Walls | Top / bottom | Infill | Notes |
|---|---|---|---|---|---|---|
| **flange_plate** | PETG (**PAHT-CF / PET-CF if you have it**) | 0.20 mm | **8** | **8 / 8** | **60 %** gyroid | Highest-stressed part. Mating face down. |
| **base_tier1** | PETG (**PAHT-CF / PET-CF if you have it**) | 0.20 mm | **8** | **8 / 8** | **50 %** gyroid | Carries the base↔flange joint. Floor down on the plate. |
| **base_tier2** | PETG | 0.20 mm | **6** | **6 / 6** | **35 %** gyroid | In the load path, with large margins. |
| **cover** | PETG | 0.20 mm | **6** | **8 / 8** | **40 %** gyroid | **The apple bolts to this.** Opaque filament — not translucent. |
| **apple_stem** | PETG | **0.15 mm** | 6 | 6 / 6 | **100 %** | See below — this one is orientation-critical. |
| **apple_retainer** | PETG | 0.15 mm | 4 | 4 / 4 | **100 %** | Flat face down. |
| **apple_ball / apple_cap** | TPU 95A | 0.20 mm | 3 | 4 / 4 | 15 % gyroid | Slow (≤ 30 mm/s), retraction near zero. |

**Temperatures.** PETG: nozzle **250 °C**, bed 80 °C, **fan 20–30 %** (not 100 %). TPU: nozzle
230 °C, bed 45 °C, fan 50 %. Enclosure closed for both, no draught.

### The apple stem — lay it down

The stem is a 100 mm cantilever. Printed upright its layers lie **perpendicular to the bending
stress** — the worst possible orientation. Printed on its own (the separate build), it can lie down:

- **Lying on its side (recommended):** layers run along the shaft, its strong axis. Tree supports
  under the Ø44 flange and the Ø20 seat; brim on. Check the root fillet came out clean.
- **Upright, if you must:** lean hard on layer adhesion — **0.15 mm layers, 255 °C, fan off for the
  first 20 mm above the flange**, 100 % infill, alone on the plate, **brim 8 mm** (the Ø24 spigot is a
  small footprint for a 120 mm part).

### Do not

- **Do not use PLA** for the plate or tier 1. Stiffer than PETG on paper, but brittle — it fails
  suddenly rather than bending, which is the wrong failure mode next to an animal.
- **Do not reduce the wall count to save time** on the plate or tier 1. Walls and solid skins are
  doing the structural work; infill percentage is the least important number in the table.

### Bambu Studio, step by step (H2D)

Sizes, so you know what you are looking at on the plate:

| Part | Footprint | Height | Material | Prints with |
|---|---|---|---|---|
| `flange_plate` | Ø124 | 16 | PETG | — |
| `base_tier1` | Ø188 | 33 | PETG | — |
| `base_tier2` | Ø188 | 32 | PETG | — |
| `cover` | Ø188 | 17 | PETG | — |
| `apple_stem` | Ø44 | 116.5 | PETG | — (lie it down) |
| `apple_ball` | Ø45 | 27.8 | TPU 95A | — |
| `apple_retainer` | Ø22 | 6 | PETG | the stem's plate |
| `apple_cap` | Ø43 | 22.5 | TPU 95A | — |
| `casing` | 198 × 198 | 77 | *not printed* | acrylic, by hand |

#### 0. Before you open Bambu Studio

- **Dry the PETG.** 65 °C for 6–8 h. This matters more than any slicer setting — see above.
- **Use the textured PEI plate for PETG.** PETG bonds *too well* to smooth PEI and can tear the
  coating off. If you only have smooth PEI, put a glue-stick layer down as a release agent.
- **TPU must come off the external spool holder, not the AMS.** Soft filament buckles in the AMS
  path.
- Optional but worth it for `base_tier1` and `flange_plate`: fit the **0.6 mm nozzle**. Fatter
  extrusions bond better between layers, which is precisely the failure mode being designed against.
  Nothing in this design needs finer than 0.6 — the smallest features are Ø3.4 holes.

#### 1. Make a process preset once, reuse it

Load any part, then in the right-hand parameter panel:

- **Quality → Layer height** `0.20`
- **Strength → Wall loops** `8`
- **Strength → Top shell layers** `8` · **Bottom shell layers** `8`
- **Strength → Sparse infill density** `50 %` · **Sparse infill pattern** `Gyroid`
- **Others → Brim type** `Outer brim only`, **Brim width** `5 mm`

Save it as a preset (the 💾 next to the process dropdown) called something like
`0.20 Structural PETG`. Now each part below is just "load this preset, change these two things".

#### 2. Filament preset

Duplicate the Bambu PETG profile and save it as `PETG - high strength`:

- **Filament → Nozzle temperature** `250 °C` (both layers)
- **Filament → Bed temperature** `80 °C`
- **Cooling → Minimum fan speed** `20 %` · **Maximum fan speed** `30 %`
- **Cooling → Keep fan always on** OFF

The low fan is deliberate. Part cooling makes PETG look nicer and bond worse, and every structural
part here fails along layer boundaries.

#### 3. Per part

**`flange_plate`** — highest-stressed part.
1. Import, **Place on bed**. It lands mating-face down, which is what you want.
2. Process: `0.20 Structural PETG`, change **Sparse infill density → 60 %**.
3. No supports. The M6 head wells are flat-bottomed and print fine.

**`base_tier1`** — carries the base↔flange joint.
1. Import, **Place on bed** (floor down).
2. Process: `0.20 Structural PETG` as-is (8 walls, 8/8 shells, 50 %).
3. No supports needed: the trenches, channels and bore ports are all open-topped or short bridges.
4. Print it **alone on the plate**. It is the one part where a failed layer matters most.

**`base_tier2`** — same shape, lower stress but still in the pull path.
1. Import, **Place on bed**.
2. Process: `0.20 Structural PETG`, then set **Wall loops → 6**, **Top/Bottom shell layers → 6**,
   **Sparse infill density → 35 %**.

**`cover`** — **more structural than it looks; the apple bolts to it.**
1. Import, **Place on bed** (ring groove facing up).
2. Process: **Wall loops 6**, **Top/Bottom 8**, **Sparse infill 40 %**. The top and bottom shells are
   the ones doing the work here: a plate in bending behaves like an I-beam and the solid skins carry
   almost all of it, so shell count buys more than infill percentage.
3. Use an **opaque** filament. The cover is the light barrier behind the ring — a translucent one
   will glow.

**`apple_cap`** — TPU, prints alone.
1. Import. It arrives at assembly height; **Place on bed** drops it. It should sit **skirt down,
   dome up**. Check this — dome-down needs supports and ruins the press-fit surface.
2. Assign the **TPU filament / nozzle**.
3. **Wall loops 3**, **Top/Bottom 4**, **Sparse infill 15 %**, **Layer height 0.20**.
4. **Speed → set everything ≤ 30 mm/s.** TPU does not survive fast corners.
5. Retraction near zero in the TPU filament profile.

#### 4. The apple — stem, ball, retainer

**`apple_stem` + `apple_retainer`** — PETG, one plate.
1. Import both. Rotate the **stem onto its side** (90° about X), **Place on bed**; the retainer
   **flat face down**.
2. **Support → Enable, type `tree(auto)`**, on build plate only — under the flange and the seat.
   **Others → Brim `8 mm`.**
3. **Layer height `0.15`**, **Sparse infill `100 %`**, **Wall loops 6**. Dry PETG, 250–255 °C, fan low.
4. Clean the supports off the flange underside and seat; the seat's top face is what the ball sits on,
   so keep it flat.

**`apple_ball`** — TPU, prints alone.
1. Import, **Place on bed**: it stands on its **flat base** (the neck pointing down, the open top up).
2. **No supports** — the underside is a 45° cone. **Brim `5 mm`**: the base is a small ring under a
   45 mm ball.
3. TPU settings as the cap: **Wall loops 3**, **Top/Bottom 4**, **infill 15 %**, **≤ 30 mm/s**,
   retraction near zero.

#### 5. Check on the first layer

- **Brim stuck down all the way round** on the stem and the ball — both stand on small footprints.
- **No gaps at the Ø30 bore wall** on `base_tier1`. It is a 4 mm ring and the first layer is where
  under-extrusion shows.
- If the first layer looks glassy and translucent rather than matte, the bed is too hot or the
  filament is wet.

## Safety (animal subject + electronics)
- Lightweight keeps tool inertia low (better impedance behaviour; gentler on contact) — the electronics
  add mass, so re-check the FRI load data / tool calibration after fitting (main repo README §2).
- The apple sits on a **PETG shaft tapering Ø24 → Ø14** (with a Ø22 retainer anchoring the TPU ball),
  integral with the cover flange. Re-check the margin after any change to
  `stem_shaft_len`; print the stem solid, and confirm the **TPU ball can't pull off the stem by hand**
  before use.
- Keep **5 V/24 V wiring** sealed under the cover and inside the clear casing box, strain-relieved;
  nothing the animal can reach or pull. The box shrouds the sides down to the flange plate, but it is
  clamped only at the centre — bond or edge-screw it to the plate if the animal could lever it.
- The cabinet's Cartesian impedance + Sunrise safety limits are the real safety layer — this tool just
  needs to be smooth, light, robustly attached (all flange bolts torqued), and electrically safe.
- First mount/move in **T1** with a hand on the E-stop.

## Reference
Barra et al., *A versatile robotic platform for … reaching and grasping tasks in monkeys*,
J. Neural Eng. 17(1):016004 (2019/2020) — same iiwa + macaque platform; silicone-over-3D-print objects
with integrated grip sensing. (Their Zenodo deposit is software-only — no object CAD — so this tool is
drawn from scratch.)

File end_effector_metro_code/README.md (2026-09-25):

# End-Effector Board Firmware — NeoPixel Cue Ring (Metro M4 AirLift)

> # ⛔ DO NOT COPY THIS FILE TO THE BOARD
> **`README.md` and `test_code.py` are repository files only — they must never be written to the
> `CIRCUITPY` drive.** When flashing or refreshing a board, copy **only** `code.py`,
> `settings.toml` and `lib/` — that is the complete payload. See [Deployment](#deployment).

CircuitPython firmware for the **Adafruit Metro M4 Express AirLift Lite** that lives in the base hub
of the [apple-pluck end effector](../end_effector_design/README.md). It drives the **60-LED RGBW
NeoPixel ring** (Adafruit 2874, Ø157) seated in the cover as a **visual cue** for the monkey.

---

## How it works

**The trigger is on/off with a timer.** When **X76 contacts 1 and 2 are shorted** at the robot
base, the short travels up the media flange to the tool connector and pulls `D2` low; the board runs
its configured cue for its configured duration, then stops. That is the entire behaviour.

**What the cue looks like is a setting, changed over the board's own Wi-Fi.** Join the board's
access point from a laptop or phone and call `/config`:

```bash
curl "http://192.168.4.1/config?r=0&g=255&b=0&w=0&pattern=segment&segments=6&duration=1.2&save=1"
```

| | **Trigger** — the wire | **Settings** — the API |
|---|---|---|
| Carries | one edge: "now" | colour, brightness, pattern, segments, duration, rate |
| Path | switch at base → X76 1/2 → flange → tool pins 9/10 → `D2` | your laptop → the board's own access point |
| When | every trial | once, at commissioning |
| Needs a network | **no** | yes, but only yours — not the robot's |

The two are separate on purpose. The trigger line is **one bit** and cannot carry a colour, and an
experiment cue must not depend on a radio link. So **the switch says *when*, and the board — already
configured by hand — decides *what*.**

```
  switch at robot base ── X76 1/2 ══ media flange ══ tool pins 9/10 ──► D2 ──► ring on, then off
  (timing only)

  your laptop ──joins KUKA_NEOPIXEL──► http://192.168.4.1/config   (what it looks like)
```

The board hosts its **own** access point and never joins another network. Wi-Fi bring-up is wrapped
in `try`/`except`, so a dead ESP32 or a bad credential drops it to trigger-only operation, running
the settings saved in NVM — it cannot stop the ring cueing.

> ### Status — firmware running, trigger path not yet commissioned
> The board has booted on real hardware (`nvm=available`, access point up) and has driven the ring
> from the cabinet's 24 V. The trigger wiring through X76 is untested, and no computer-controlled
> switch is fitted yet — see [Driving the trigger](#driving-the-trigger-from-ros-2). Until then,
> demos fire the cue over Wi-Fi with the [demo trigger](#demo-trigger-over-wi-fi).

---

## Contents
- [Hardware context](#hardware-context)
- [The cue trigger — wiring](#the-cue-trigger--wiring)
- [Architecture](#architecture)
- [Settings](#settings)
- [Power — read before raising brightness](#power--read-before-raising-brightness)
- [Files on the board](#files-on-the-board)
- [HTTP API](#http-api)
- [Deployment](#deployment)
- [Testing](#testing)
- [`settings.toml` — Wi-Fi credentials](#settingstoml--wi-fi-credentials)
- [Changing the firmware without USB](#changing-the-firmware-without-usb)
- [Driving the trigger from ROS 2](#driving-the-trigger-from-ros-2)
- [Known limitations](#known-limitations)

---

## Hardware context

| | |
|---|---|
| **Board** | Adafruit Metro M4 Express AirLift Lite ([4000](https://www.adafruit.com/product/4000)), `samd51j19` |
| **Firmware** | CircuitPython **10.1.4** |
| **Wi-Fi** | ESP32 **co-processor over SPI** — *not* native Wi-Fi (this is why the code uses `adafruit_esp32spi`, not `wifi`) |
| **LED ring** | 60 × 5050 **RGBW**, Adafruit [2874](https://www.adafruit.com/product/2874), bought as 4 quarter-arcs |
| **Ring data** | `board.D5` → **Pixel Shifter** ([6066](https://www.adafruit.com/product/6066), 3.3 V → 5 V) → ring `DIN` |
| **Cue input** | `board.D2` ← tool connector pin 9, via X76 contact 1 at the robot base (internal pull-up, active low) |
| **Power** | cabinet 24 V via the X650/X651 data cable → tool pins 1/2 → Tobsun 24 V→5 V → board **and** ring (5 V injected at all 4 quarter joints) |

```
   MEDIA FLANGE (Inside electric) — a pass-through, no electronics
   │
   ├─ tool pins 1/2  ── 24 V from the cabinet ──► Tobsun 24 V → 5 V ──┬──► Metro M4 AirLift
   │                                                                 │     ├ SAMD51 (code)
   │                                                                 │     └ ESP32 (Wi-Fi)
   │                                                                 │
   │                                                                 └──► NeoPixel ring
   │                                                                      (5 V at all 4 quarter joints)
   │
   └─ tool pins 9/10 ── CTR1, shorted at X76 1-2 by the trigger switch ──► Metro D2 / GND

   Metro D5 ── 3.3 V data ──► Pixel Shifter ── 5 V data ──► ring DIN
```

> **⚡ Current is not capped in firmware — see [Power](#power--read-before-raising-brightness).**
> `brightness` is settable to 1.0, and at 1.0 the ring can draw up to **~4.8 A at 5 V**. The
> default of `0.2` is a conservative starting point, not a measured limit for your build. Never
> feed the ring from the Metro's own 5 V pin.

---

## The cue trigger — wiring

The trigger is a **contact closure**. Shorting X76 contacts 1 and 2 at the robot base connects `D2`
to `GND` through the media flange's CTR1 pair; the Metro's internal pull-up holds `D2` high the rest
of the time.

```
   robot base                  media flange (pass-through)             end effector

   X76 contact 1 ──┐                                                ┌── tool pin 9  (BK) ──► D2
                   ├─ switch ═══════ CTR1 shielded pair ════════════┤
   X76 contact 2 ──┘                                                └── tool pin 10 (BU) ──► GND

   X76 contact 3 ── CTR1 drain — bond here only; tool pin 11 (WH) stays insulated
```

| Tool connector | Colour | Connect to |
|---|---|---|
| pin **9** (CTR1_1) | BK | Metro **`D2`** |
| pin **10** (CTR1_2) | BU | Metro **`GND`** |
| pin 11 (CTR1_3, drain) | WH | insulated — the drain is bonded at the base |

**Polarity — `active_low` (default `1`):** the internal pull-up holds `D2` high, so **idle = HIGH**
and **cue asserted = LOW**. This is the safe polarity: an unplugged connector, an open switch, or a
broken wire all read as *no cue* rather than a stuck-on cue.

**No optocoupler is needed** as long as the switch is a floating contact — a jumper, or a relay's
dry contacts. The only voltage in the loop is the Metro's own 3.3 V. Anything that *outputs* a
voltage onto X76 1/2 is different: 24 V on `D2` destroys the SAMD51, so that must go through an
optocoupler — and since optocoupler output stages often invert, flip polarity over Wi-Fi rather than
opening the effector:

```bash
curl "http://192.168.4.1/config?active_low=0"   # switches the pin to an internal pull-down
```

The firmware resynchronises the debouncer as part of the change, so flipping polarity does not
itself look like an edge and fire a spurious cue.

For a production build, add an external **4.7 kΩ pull-up** from `D2` to 3.3 V. The internal pull-up
is weak, and the line runs several metres past seven joint drives.

### Bench-testing without the robot

You do not need the robot to verify the firmware. With the board on USB:

```
jumper D2 ──► GND     = cue asserted  (ring flashes)
remove jumper         = idle
```

Then confirm what the board actually sees over Wi-Fi:

```bash
curl http://192.168.4.1/status | grep trigger
# trigger_pin_raw=False        <- raw pin level
# trigger_asserted=True        <- after applying the active_low setting
# trigger_debounced=True       <- what the edge detector acted on
```

Those three lines together tell you whether a "the cue does not fire" problem is in the wiring, the
polarity setting, or the firmware.

---

## Architecture

Everything is one file, [`code.py`](code.py), which CircuitPython runs automatically at boot and
re-runs on every save. Bring-up is ordered so the primary path never depends on the secondary one:

```
 1. PIXEL SETUP      neopixel.NeoPixel(D5, 60, brightness=0.2,
                                       auto_write=False, pixel_order=GRBW)
        │            auto_write=False ⇒ writes are buffered until pixels.show()
        ▼
 2. BOOT INDICATOR   two short dim-white flashes — proves the board booted and the ring
        │            is wired, visible from outside a closed effector
        ▼
 3. LOAD SETTINGS    microcontroller.nvm → cfg, if a valid record is stored;
        │            otherwise DEFAULTS. Corrupt or absent NVM is not an error.
        ▼
 4. CUE INPUT        D2 as input, internal pull-up (or pull-down if active-high)
        │            ◄── the primary path is live from here on
        ▼
 5. WIFI + HTTP      ESP32 over SPI → create_AP() → Server(...).start(192.168.4.1, 80)
        │            ENTIRELY inside try/except: on failure, log and continue with
        │            server = None. The cue path is unaffected.
        ▼
 6. MAIN LOOP        while True: poll_trigger() ; cue_service() ; server.poll()
```

### The main loop

```python
while True:
    poll_trigger()          # debounced edge detect on D2  -> may start/stop a cue
    cue_service()           # advance the flash animation   -> non-blocking
    led_test_service()      # step /led_test, if running    -> non-blocking
    if server is not None:
        server.poll()       # handle at most one HTTP request -> non-blocking
```

**Nothing in this loop sleeps and no route handler sleeps.** That is the property that makes the
whole design work: a cue animates while HTTP requests are being served, and HTTP traffic cannot
delay a cue beyond one short loop pass. Trigger latency is therefore ≈ the `debounce_ms` setting.

### The cue engine

A cue is state, not a blocking sequence:

```
cue_start(color, duration, period, pattern)
    ├─ snapshot the current ring contents      (restored when the cue ends)
    ├─ _cue_until_ns = now + duration          (or -1 for "until stopped")
    └─ render the frame at phase 0

cue_service()   ← every loop pass
    ├─ past _cue_until_ns? ──────► cue_stop(): restore the snapshot
    ├─ pattern "solid"     ──────► nothing to animate, return
    ├─ phase = ((now - start) % period) / period
    ├─ "flash" → redraw only when the half-period boundary is crossed
    └─ others  → redraw at a fixed ~30 fps, timed from *now* rather than by
                 accumulation, so a slow loop pass cannot queue up a burst
                 of catch-up frames
```

Snapshot/restore makes a cue **non-destructive**: if the ring was showing something before the cue —
a solid colour, a segment pattern — it comes back afterwards. A manual HTTP command arriving
mid-cue cancels it (`cue_stop(restore=False)`) and wins, because an operator at a browser is
deliberately overriding.

### Trigger modes

`mode` decides who owns the cue's length:

| Mode | Behaviour | Use when |
|---|---|---|
| **`pulse`** *(default)* | An asserted edge starts the cue, which runs for its configured **`duration`** and stops. The line may drop immediately. | Normal use — on and off with the board's timer. |
| `follow` | The cue runs for **exactly as long as the line is held**; `duration` is ignored. | You want the cabinet to own cue length, the way it owns `AudioCue` length. |

`retrigger=0` (the default) makes a second edge arriving mid-cue a no-op, so contact bounce or a
double-pulse cannot restart the cue.

## Settings

**This is the whole configurable surface of the board**, and all of it lives behind one endpoint,
`/config`. Every field is independent: send any subset and the rest is unchanged.

```bash
curl http://192.168.4.1/config                                  # read everything
curl "http://192.168.4.1/config?r=0&g=255&b=0&w=0"              # colour
curl "http://192.168.4.1/config?brightness=0.3&duration=1.2"    # brighter, shorter
curl "http://192.168.4.1/config?pattern=segment&segments=6"      # look
curl "http://192.168.4.1/config?save=1"                          # keep across reboots
curl http://192.168.4.1/cue                                      # try it without the wire
```

### What the cue looks like

| Field | Values | What it does |
|---|---|---|
| `r` `g` `b` `w` | 0–255 | colour (`w` is the dedicated white channel — cleaner than `r=g=b`) |
| `pattern` | `flash` `solid` `breathe` `chase` `segment` | the cue modality |
| `segments` | 1–30 | lit blocks, for the `segment` pattern |
| **`duration`** | 0.05–300 s | **the timer** — how long the ring stays on after a trigger |
| `period` | 0.02–10 s | one full cycle of the pattern |

| Pattern | Behaviour | Update rate |
|---|---|---|
| `flash` | square on/off at `period` | boundary only |
| `solid` | steady for `duration` | drawn once |
| `breathe` | smooth raised-cosine fade in/out | ~30 fps |
| `chase` | a lit arc of 8 LEDs rotating once per `period` | ~30 fps |
| `segment` | `segments` lit blocks evenly spaced, flashing together | boundary only |

### How the board behaves

| Field | Values | What it does |
|---|---|---|
| `brightness` | 0.0–1.0 | scales the whole ring. **Not capped — [read this](#power--read-before-raising-brightness).** |
| `mode` | `pulse` `follow` | who owns the cue's length — `duration`, or the wire |
| `active_low` | 0 / 1 | trigger polarity — **flip this if the trigger reads inverted, without opening the box** |
| `debounce_ms` | 1–200 | how long the input must hold a level |
| `retrigger` | 0 / 1 | may a new edge restart an in-flight cue |
| `enabled` | 0 / 1 | arm/disarm the wire entirely |

### Power — read before raising `brightness`

**`brightness` is the only scale, and it is deliberately not capped in firmware.** It multiplies
the ring's current draw very nearly linearly, and keeping that inside what the hardware can deliver
is the operator's call, not something the firmware should quietly decide for you.

At `brightness = 1.0`, 60 SK6812 RGBW LEDs draw roughly:

| Colour | Per LED | 60 LEDs |
|---|---|---|
| `w=255` only | ~20 mA | **~1.2 A** ← the white channel is the cheap one |
| `r=g=b=255, w=0` | ~60 mA | **~3.6 A** |
| `r=g=b=w=255` | ~80 mA | **~4.8 A** ← absolute worst case |

Multiply by `brightness` for the actual draw. The default cue (`w=255`, `brightness=0.2`) is about
**0.24 A**.

Before raising it, check **all** of:

- **The Tobsun 24 V→5 V converter's rating**, and its derating when warm. This is the usual limit.
- **The 5 V wiring gauge** down the flange bore. Several amps through thin wire means voltage drop,
  heat, and visible colour shift at the far end of the ring.
- **That 5 V is injected at all four quarter-ring joints.** Feeding 60 LEDs through one arc's
  traces browns out the far end and overheats the near end — the ring is bought as 4 arcs for
  exactly this reason.
- **Temperature inside the closed casing box.** The effector is handled by an animal, so surface
  temperature is a subject-safety limit, not just an electronics one.
- **How bright the cue actually needs to be.** A cue is a *signal*, not illumination, and the ring
  sits centimetres from the subject's face. The lowest brightness that reads reliably is the right
  one — for the subject as much as for the wiring.

**Never feed the ring from the Metro's own 5 V pin**: that comes off the board regulator and cannot
source anything close to these currents.

### Persistence — NVM, not a file

`/config?save=1` writes every setting above to `microcontroller.nvm`, restored at the next boot.
Without it, the board comes back with the defaults in `code.py`.

> **Why NVM and not a config file?** Writing any file from firmware requires `storage.remount()`
> in `boot.py`, which makes **CIRCUITPY read-only to your computer** and puts a boot-time failure
> between you and a working board. NVM has neither cost. See
> [Changing the firmware without USB](#changing-the-firmware-without-usb).

The record is magic-tagged, versioned and checksummed; a corrupt record falls back to the defaults
rather than failing to boot.

NVM **is** present on this board — `/status` reports `nvm=available`. The firmware still falls back
to a RAM buffer if a build ever lacks it, and that is about the *failure mode*, not the
probability: `nvm_load()` runs at module scope, **before the trigger is set up**, so an unguarded
access on a missing `nvm` would stop `code.py` before `poll_trigger()` exists and the ring would
fire nothing at all. The fallback costs two lines and lets `nvm_save`/`nvm_load`/`nvm_clear`
contain no presence checks at all — they always work, and the only difference is whether values
outlive a reboot. In that case `/status` reads `nvm=RAM ONLY (not persistent)` and `save=1` says
`saved to RAM ONLY`, so it never pretends.

#### Is repeated saving bad for the board?

`microcontroller.nvm` is a reserved region of the SAMD51's internal flash, and a write is an
erase-and-program of a flash row. That has a finite endurance — **~25,000 cycles** per the SAMD51
datasheet (confirm for your exact part). Three things keep it a non-issue:

- **Saving is never automatic.** `nvm_save()` has exactly one caller: `/config?save=1`. There is
  no timer, no save-on-change, no save-on-shutdown. Tuning over `/config` is free; only the
  explicit save writes.
- **An identical save costs nothing.** The firmware packs the record, compares it to what is
  already stored, and returns without touching flash if they match. Re-saving the same settings,
  or a script that loops on `save=1`, does **zero** writes. `reset=1` on an already-cleared record
  is likewise free.
- **The counter is visible.** `/status` reports `nvm_writes` — actual flash writes since power-up.
  If a script is saving more than you expect, it shows up there instead of quietly eating cycles.

So the cycle count advances only when the stored settings genuinely change. At a handful of real
changes per commissioning session, 25,000 cycles is thousands of sessions — not a limit you will
reach by hand.

**If it ever did wear out**, the failure is benign: the row stops holding the value, the checksum
fails at boot, and the board falls back to the defaults in `code.py`. Settings stop persisting;
nothing bricks, and the trigger keeps working. NVM is a separate region from the CIRCUITPY
filesystem, so wear there cannot touch `code.py`.

**Power loss mid-write** is the other risk worth naming — the arm's 24 V can vanish at any moment.
A half-written record fails its checksum on the next boot and is rejected wholesale, so the board
comes up on defaults rather than on a corrupted config. Save while the arm is idle, not mid-trial.

`/config?reset=1` restores the defaults and invalidates the record.

> **Values are quantised by the save.** `brightness` is stored as one byte (~0.4% steps) and
> `duration`/`period` as centiseconds. Read back after a save, `brightness=0.9` returns `0.898`.
> Colour components are bytes already, so those round-trip exactly.

## Files on the board

Only `code.py` and `settings.toml` run on the board as our code; `lib/` is the Adafruit library
bundle, and `README.md` never leaves the repo.

| Path | Origin | Deploy to board? | Notes |
|---|---|---|---|
| **`code.py`** | **ours** | **yes** | The entire application. Auto-run and auto-reloaded by CircuitPython. |
| **`settings.toml`** | **ours** | **yes** | AP SSID + password. See [below](#settingstoml--wi-fi-credentials). |
| **`lib/`** | Adafruit bundle | **yes** | `.mpy` libraries, below. |
| `README.md` | **ours** | **no** | This document. Repository documentation only. |
| **`test_code.py`** | **ours** | **no** | Offline test suite — see [Testing](#testing). Never copy it to the drive. |

The board's own drive also carries `boot_out.txt` (written *by* CircuitPython at boot — firmware
version, board ID, UID) and the zero-byte macOS indexing suppressors `.fseventsd/no_log`,
`.metadata_never_index` and `.Trashes`. **Leave all of those on the board**; none are mirrored here,
because none are ever deployed *from* the repo. Nothing else belongs on the drive: `code.py` needs
only the files listed here.

### `lib/` — what is actually required

| Library | Why |
|---|---|
| `neopixel.mpy` | Drives the ring. (`adafruit_pixelbuf` is built into the CircuitPython core on this board.) |
| `adafruit_esp32spi/` | ESP32 co-processor driver + the `socketpool` shim the HTTP server sits on. |
| `adafruit_httpserver/` | The routing / request / response layer. |
| `adafruit_bus_device/` | SPI transaction helper — a dependency of `adafruit_esp32spi`. |

`lib/` holds exactly these four. Leave everything *inside* `adafruit_esp32spi/` as it
is — the package imports its own submodules internally, so its apparent duplicates (`socketpool` vs
`adafruit_esp32spi_socketpool`, `wifimanager` vs `adafruit_esp32spi_wifimanager`) are not spare
copies to prune.

---

## HTTP API

**Secondary path.** All routes are **GET**, served at `http://192.168.4.1/` once you have joined the
`KUKA_NEOPIXEL` network. Colour components are `r`, `g`, `b`, `w`, each `0–255`.

> **Colour ordering.** `pixel_order=GRBW` is the **wire** order the LEDs expect; the library handles
> that reordering internally. In the API and in code you always pass values in **R, G, B, W** order.

> **Every route returns immediately.** No handler blocks — flashes are handed to the cue engine and
> animated by the main loop.

| Route | Parameters | Effect |
|---|---|---|
| **`/config`** | any setting, plus `save=1` / `reset=1` | **The whole configurable surface.** No parameters = read-only. |
| **`/cue`** | — | Run the configured cue **now**, without the wire. |
| **`/status`** | — | Everything `/config` shows, plus the **live trigger-pin state**, fire count and uptime. First stop when debugging. |
| `/off` | — | Clear the ring and cancel a running cue. |
| `/set_color` | `r` `g` `b` `w` | Hold a solid colour (not a cue — it does not time out). |
| `/segments` | `factor`, `colors` | Static arcs. For a *timed* segmented cue use `pattern=segment`. |
| `/led_test` | `from`, `to` (pixel 0–59), `step` (seconds per colour, 0.05–5, default 0.25), `loop=1` | **Diagnostics.** Lights one LED at a time in red, green, blue, then white, walking the ring. `/status` shows `led_test_pixel` while it runs; `/off` stops it. |
| `/fs` | — | List what is on the board, with sizes. |
| `/fs/get` | `path` | Read a text file back (`code.py`, `*.txt`, `*.json`). **Read-only** — see [below](#changing-the-firmware-without-usb). |

### Examples

Join the board's access point (`KUKA_NEOPIXEL`) first — it is always at **192.168.4.1**.

```bash
# what is the board doing right now?  (settings, trigger pin, fire count, uptime)
curl http://192.168.4.1/status
```

**Set what the cue looks like — this is the part that replaces editing `code.py`:**

```bash
# dim green, six segments, 0.8 s
curl "http://192.168.4.1/config?r=0&g=255&b=0&w=0&pattern=segment&segments=6&duration=0.8"

# change ONE field; everything else carries over
curl "http://192.168.4.1/config?brightness=0.35"
curl "http://192.168.4.1/config?pattern=breathe&period=1.2"
curl "http://192.168.4.1/config?duration=2.5"

# try it without the robot, then keep it across reboots
curl http://192.168.4.1/cue
curl "http://192.168.4.1/config?save=1"
```

**How the board behaves:**

```bash
curl "http://192.168.4.1/config?mode=follow"        # let the wire own cue length
curl "http://192.168.4.1/config?brightness=0.25"    # READ THE POWER SECTION FIRST
curl "http://192.168.4.1/config?active_low=0"       # trigger reads inverted
curl "http://192.168.4.1/config?enabled=0"          # disarm the wire while you work on it
curl "http://192.168.4.1/config?reset=1"            # back to the defaults in code.py
```

**Manual control and read-back:**

```bash
curl "http://192.168.4.1/set_color?w=255"
curl http://192.168.4.1/off
curl http://192.168.4.1/fs                          # what is on the drive
curl "http://192.168.4.1/fs/get?path=code.py"       # confirm what is actually running
```

**Finding where a partly-dark ring stops:**

```bash
curl http://192.168.4.1/led_test                            # every LED, 4 colours each (~1 minute)
curl "http://192.168.4.1/led_test?from=43&to=48&step=1"     # slowly, across the joint into the last arc
curl "http://192.168.4.1/led_test?from=46&to=46&loop=1"     # hold one LED cycling while you probe it
curl http://192.168.4.1/status | grep led_test              # which pixel is lit right now
curl http://192.168.4.1/off                                 # stop
```

The ring is four arcs of 15 LEDs: pixels **0–14, 15–29, 30–44, 45–59**, in data order (the arc the data
wire lands on is pixel 0). Reading the result:

- **One LED lit at a time draws almost nothing**, so a pixel that stays dark in this test is *not* the
  supply sagging under load. It is a data joint, a dead LED, or an arc with no 5 V of its own.
- **An arc with data but no 5 V/GND can light its *first* LED dimly** — powered through the data
  line — while the rest of it stays dark. If the dark section starts one LED into an arc, measure
  5 V across that arc's pads before suspecting the LEDs.
- **5 V present, but the walk stops at the same pixel every time:** that LED passes no data on. The
  first LED next to a soldered joint is the usual casualty of soldering heat.

### `/segments` format

`colors` is a **`.`-separated list of segments**, each a **`,`-separated** `R,G,B[,W]` group:

```
colors = 255,0,0,0 . 0,255,0,0 . 0,0,255,0 . 0,0,0,255
          └ seg 0 ┘  └ seg 1 ┘  └ seg 2 ┘  └ seg 3 ┘
```

The `.` separator works only because every component is an integer — never introduce decimals here.
Segments beyond `factor` are ignored; a 3-value segment is auto-padded with `W=0`; a malformed
segment is skipped with a message on the serial console rather than failing the request.

> **Segment size truncates.** `seg_size = 60 // factor`. Any factor that does not divide 60 leaves
> the remaining pixels **dark** — e.g. `factor=7` lights 7 × 8 = 56 LEDs and leaves 4 off. Clean
> divisors of 60: **2, 3, 4, 5, 6, 10, 12, 15, 20, 30**.

---

## Deployment

CircuitPython presents the board as a USB mass-storage drive named **`CIRCUITPY`**. Deployment is a
plain file copy; **saving `code.py` makes the board reload and re-run it immediately** — there is no
build, flash, or reset step.

```bash
# Linux / WSL2 — the drive mounts through Windows, so it appears under /mnt/<letter>
ls /mnt/d/                                      # confirm you see code.py — i.e. the right drive
cp end_effector_metro_code/code.py /mnt/d/code.py
```

On Windows just copy to the `CIRCUITPY:` drive in Explorer; on macOS to `/Volumes/CIRCUITPY`.

**For a fresh board**, copy exactly three things — and nothing else:

```bash
cp end_effector_metro_code/code.py       /mnt/d/
cp end_effector_metro_code/settings.toml /mnt/d/
mkdir -p /mnt/d/lib
cp -r end_effector_metro_code/lib/. /mnt/d/lib/    # note the /. — `cp -r lib /mnt/d/lib` would
                                                   # nest it as /mnt/d/lib/lib on an existing board
```

A board straight from Adafruit already has a populated `lib/`; this copy adds ours **alongside**
those files rather than replacing them. Delete the factory-demo libraries off the drive
(`simpleio`, `adafruit_dotstar`, `adafruit_hid/`, `adafruit_waveform/`) to match this folder.

**Never copy `README.md` or `test_code.py` to the drive**, and never copy the board's
`boot_out.txt` back over itself —
it is the board's own record of the installed firmware. Leave the board's `.fseventsd/`,
`.metadata_never_index` and `.Trashes` in place.

**To pull the board's state back into this repo**, copy `code.py` (and `lib/` if you changed it) in
the other direction, and **mask the Wi-Fi password before committing** (see below).

### Serial console (REPL)

`code.py` prints the cue-pin configuration, the ESP32 firmware version and MAC, the server URL, any
Wi-Fi bring-up failure, every HTTP request (`debug=True`), and any exception from the poll loop.
Watch it while debugging:

```bash
# WSL2 cannot see USB serial directly — use PuTTY / Tera Term on the Windows side at 115200 baud,
# or attach the device with usbipd-win first.
screen /dev/ttyACM0 115200      # native Linux
```

`Ctrl-C` in the REPL stops `code.py`; `Ctrl-D` reloads it.

---

## Testing

[`test_code.py`](test_code.py) runs the **real firmware** on a desktop — no board, no
dependencies, nothing to install:

```bash
python3 end_effector_metro_code/test_code.py     # exits non-zero on failure
```

It stubs CircuitPython's modules in-process (`board`, `neopixel`, `digitalio`, the ESP32 driver,
the HTTP server, `microcontroller.nvm`) and replaces `time.monotonic_ns` with a virtual clock, so
a 2.5 s cue costs no real time and the suite cannot flake on a slow machine. `code.py` is then
executed up to — but not including — its `while True:` loop, which leaves every function and route
handler callable directly.

**121 checks**, covering the things that are painful to discover on hardware:

| | |
|---|---|
| The trigger | on at the edge, off when the timer expires, stays on after the line drops, several durations |
| Polarity & debounce | `active_low` flip does not fire a spurious cue, sub-debounce pulses are ignored, `retrigger`, `follow`, `enabled=0` |
| Settings | fields compose, bad input keeps the old value, brightness clamps to 0–1, colour is unrounded |
| Persistence | full round trip through NVM, and a **corrupt record is rejected wholesale** rather than half-loaded |
| Degradation | **Wi-Fi down → the wire still fires the cue** |
| Patterns | each renders distinctly, and **every one is lit at phase 0** so a cue has a crisp onset |
| Cue hygiene | a cue restores what the ring was showing; a manual command cancels it and wins |
| LED test | exactly one LED lit per step, every LED through all four colours in order, `from`/`to`/`loop`, and a cue or manual command stops it without leaving a test pixel behind |
| File access | read-only, refuses `settings.toml`, refuses traversal, no write route |
| Surface | the HTTP endpoints are exactly the documented set, and `/status` reports every documented field |

**What it does not cover:** anything physical — the flange wiring, the real ESP32, LED timing,
current draw. It checks logic, not electrons. Still bench-test with a jumper on `D2`
([above](#bench-testing-without-the-robot)) before trusting a build on the arm.

Run it after any edit to `code.py`, before copying to the board.

---

## `settings.toml` — Wi-Fi credentials

CircuitPython parses `settings.toml` at boot and exposes its keys through `os.getenv()`:

```toml
CIRCUITPY_WIFI_SSID = "KUKA_NEOPIXEL"
CIRCUITPY_WIFI_PASSWORD = "your-ap-password"
```

Two things worth knowing:

1. **These key names are borrowed, not magic here.** On boards with *native* Wi-Fi, CircuitPython
   reads them to auto-join a network as a *client*. This board has no native Wi-Fi, so nothing
   automatic happens — `code.py` reads them itself and uses them to **create an AP**.
2. **⚠️ The committed copy has the password masked out (`####`), and that masked form is not valid
   TOML** — `#` starts a comment, so the value is lost and `os.getenv()` returns `None`. This is
   deliberate (the real credential is not in the repo), but it means **you must write a real, quoted
   password onto the board's own `settings.toml`** before the Wi-Fi path will come up. WPA2 requires
   **8–63 characters**.

   The firmware detects this case explicitly and prints
   `WiFi/HTTP unavailable: CIRCUITPY_WIFI_SSID / CIRCUITPY_WIFI_PASSWORD missing …` rather than
   dying — **the hardwired cue still works on a board with no valid credentials.**

---

## Changing the firmware without USB

The board ends up bolted inside a closed effector, so "do I have to open the box?" is a real
operational question. The answer depends on *what* you are changing.

| You want to change | Needs USB? | How |
|---|---|---|
| Cue colour, length, rate, **pattern**, brightness | **No** | `/config?...` |
| Trigger polarity, debounce, mode, arm/disarm | **No** | `/config?...` |
| Any of the above, permanently | **No** | `/config?...&save=1` (NVM) |
| Read back what is on the board | **No** | `/fs`, `/fs/get?path=code.py` |
| **Write** new code to the board | **Yes** | copy `code.py` to the drive |
| Debug a crash, read a traceback | **Yes** | USB serial — see [Serial console](#serial-console-repl) |

That split is deliberate: **tuning is a request, new behaviour is a code change.** The runtime
settings cover the cases that would otherwise send you to the USB port for a one-line edit.

### Why there is no upload endpoint

CircuitPython's built-in **Web Workflow** — browser file manager + REPL over Wi-Fi — is exactly the
feature this calls for, and it is **not available on this board**. Web Workflow requires *native*
Wi-Fi (the core `wifi` module); here the Wi-Fi is an **ESP32 co-processor driven by a Python
library**, so the core has no networking to serve it from. Confirm in the REPL — this fails:

```python
import wifi        # ImportError on metro_m4_airlift_lite
```

*(This is also why `CIRCUITPY_WIFI_SSID` / `CIRCUITPY_WIFI_PASSWORD` do nothing automatically:
they are Web Workflow's settings keys, and `code.py` has to read them by hand.)*

A custom upload endpoint is possible — the bundled `adafruit_httpserver` is **4.8.1**, which has
`POST` and `request.body` — but it is not shipped, because the write side is where the costs are.
**Reading files needs nothing; writing them changes how the board boots:**

1. Writing any file from firmware requires `storage.remount("/", readonly=False)` in `boot.py`,
   and from then on **CIRCUITPY is read-only to your computer.** You trade USB editing for Wi-Fi
   editing rather than gaining both. A jumper read in `boot.py` can switch between them — but you
   have to open the box to move it.
2. **`boot.py` runs before `code.py`.** If it raises, CircuitPython enters **safe mode** and never
   runs `code.py` at all: no Wi-Fi, no cue, USB-only recovery.
3. **One bad `code.py` upload takes the Wi-Fi server with it** — the script dies before
   `server.start()`, so the only way back in is the USB port you were trying to avoid.
4. Flash wear, and filesystem corruption if the arm's 24 V drops mid-write.

### If you decide you want it anyway

Do not OTA `code.py` directly — use a **loader pattern**, which makes bricking essentially
impossible:

- `code.py` stays small, stable and **never uploaded**. It brings up Wi-Fi and the upload endpoint
  **first**, then `try: import app` for the real logic.
- A broken `app.py` logs the traceback and leaves the network up, so you can push a fix.
- **Never** put `settings.toml` or `lib/` in the upload path: a bad `settings.toml` kills Wi-Fi at
  boot with no recovery but USB, and `lib/` is 57 KB of binaries that change approximately never.
- `adafruit_httpserver` buffers the whole request in `request_buffer_size` (default **1024 B**) and
  `code.py` is ~26 KB, so chunk the upload with an offset parameter rather than raising the buffer
  on a 192 KB-RAM part.
- Internal writes do not trigger auto-reload; call `supervisor.reload()` yourself.

### The alternative worth considering first

A **panel-mount USB extension** from the Metro out to the casing wall. It solves the actual problem
— physical access — with no software risk, keeps the drive read-write, and gives you the **serial
console**, which no amount of OTA can: `/status` reports the trigger pin, but boot failures and
exception tracebacks only ever appear on serial.

---

## Driving the trigger from ROS 2

### How the short reaches the board

This arm's **Media flange Inside electric** is a pass-through: whatever is connected at the robot
base appears at the tool connector. The trigger uses the shielded pair **CTR1**:

```
   X76 contact 1 ── CTR1_1 ══ flange ══ tool connector pin 9  (BK) ──► Metro D2
   X76 contact 2 ── CTR1_2 ══ flange ══ tool connector pin 10 (BU) ──► Metro GND
```

Shorting contacts 1 and 2 at the base pulls D2 to ground through the whole harness. The firmware's
`active_low` default and D2's internal pull-up mean **a bare contact is a valid trigger** — no power
and no optocoupler. Full pinout in
[`end_effector_design/README.md`](../end_effector_design/README.md#tool-connector-pinout).

### What closes the switch

**Not the cabinet.** The flange has no cabinet-driven I/O and the Sunrise project has no generated
I/O groups, so Sunrise has no output that could drive X76.

**Driven by the ROS computer, over an RS‑422 serial link — decided, parts on order.** The pressure
sensor needs a data channel off the tool anyway, and one differential link carries both; a
dry-contact relay on X76 1/2 would be two orders of magnitude slower (5–15 ms mechanical against
~80 µs of wire time). StarTech ICUSB422IS
on the ROS box, MikroE MIKROE‑2821 at the tool; wiring in
[`end_effector_design/README.md`](../end_effector_design/README.md) step 4.

**What the firmware will need.** A `busio.UART` on the MikroE's pins, a framed command parser, and a
handler shaped exactly like `fire_cue` — which already lights the ring *before* it replies:

```python
def fire_cue(request):
    cue_start(cfg)             # -> _render(0.0) -> pixels.show()   ring lit HERE
    return Response(request, ...)   # reply goes out AFTER
```

Mirror that on serial and write an ack **immediately after `cue_start()` returns**. That ack is a
per‑trial cue‑delivery timestamp accurate to ~2 ms with no extra hardware, which is what cue‑locked
neural analysis needs. The ROS side already logs `cue_visual_ack` from the Wi‑Fi path's equivalent.

> **Optocoupler or not?** Not on the inbound trigger: the only voltage in that loop is the Metro's
> own 3.3 V. The *outbound* direction is different — anything the Metro drives toward a 24 V cabinet
> input needs one, as does anything that puts a voltage onto X76 1/2. 24 V on `D2` destroys the
> SAMD51.

For a production build, add an external **4.7 kΩ pull-up** from D2 to 3.3 V at the board. The
internal pull-up is weak, and the line runs several metres past seven joint drives.

### Commissioning it

Short X76 1–2 by hand and watch what the firmware saw:

```bash
python3 sinthlab_bringup/diagnostics/check_cue_wiring.py      # from a laptop on KUKA_NEOPIXEL
```

It pre-flights the board — catching `enabled=0`, a cue too dim or short to see, and **inverted
polarity** — then announces every edge. The full sequence, including the continuity checks that must
come first, is the
[commissioning checklist](../end_effector_design/README.md#commissioning-the-trigger--do-it-in-this-order).

### The ROS side

[`sinthlab_bringup/actions/visual_cue.py`](../sinthlab_bringup/sinthlab_bringup/actions/visual_cue.py)
mirrors `AudioCue` and is called beside it at every cue site — all four experiments, eight sites.
Two parameters in the shared `visual_cue` block drive it: `enabled` turns visual cues on or off, and
`remote_test_trigger` picks how they fire — `true` over Wi-Fi ([below](#demo-trigger-over-wi-fi)),
`false` over the wire. **The wire path is a safe no-op until the switch is fitted:** `start()`
completes immediately, and `VisualCue.warmup()` warns once. The experiments run unchanged.

When the relay arrives, implement `VisualCue._close_switch()` and set `remote_test_trigger: false` —
nothing else changes. Keep the closure short (it only has to outlast the board's 5 ms debounce; the
board's own `duration` decides how long the ring stays lit), and make sure it can never raise or
block the orchestrator.

### Demo trigger over Wi-Fi

For demos and recordings the experiments can fire the cue over the board's access point, with no
wire at all. In the experiment's YAML:

```yaml
visual_cue:
  enabled: true                 # on in the apple pluck, perturb and maze configs
  remote_test_trigger: true
  colours:                      # optional: [r, g, b, w] per cue site
    play: [0, 255, 0, 0]        # green
    snap: [255, 0, 0, 0]        # red
```

Join the ROS computer to **`KUKA_NEOPIXEL`** — its Ethernet link to the robot is separate — and
check the link from the shell you launch from with `curl http://192.168.4.1/status`. Each cue site
then sends `GET /cue`. A site with a colour configured first sets it with `/config?r=0&g=255&b=0&w=0`,
then sends `/cue`. There is no `save=1`, so nothing is written to flash, and it needs nothing the
firmware on the board does not already have. The board keeps that colour until the next cue sets
another, or a reboot restores its saved colour. Pattern, duration and brightness still come from the
board's settings. The cue sites are `play` and `snap` in apple pluck and perturb, and
`play`, `reward`, `goal` and `timeout` in the maze.

- **It never stalls a trial.** Requests go out one at a time from a background thread, and
  `start()` returns at once.
- **Everything is logged.** At startup, whether the board answered; then each cue with its
  round-trip time, or why it failed.
- **A late cue is dropped, not shown.** A cue still waiting behind a slow request after 0.5 s is
  skipped and logged.
- **Not for experiments.** The Wi-Fi delay varies from cue to cue. Align trial data to the wire,
  never to this.

The code is one self-contained file:
[`visual_cue_remote.py`](../sinthlab_bringup/sinthlab_bringup/actions/visual_cue_remote.py).

### On timestamping the cue against motion

Log the ROS time at which `_close_switch()` fires; that puts the cue on the same clock as the
trajectory. What it does *not* tell you is when the light appeared. Between the two sit the switch's
closing time (a few milliseconds for a mechanical relay, microseconds for a solid-state one), the
board's debounce (`debounce_ms`, 5 ms by default) and one LED refresh (~2.4 ms for 60 RGBW pixels).
That offset is mostly fixed: **measure it once with a photodiode and a scope** rather than assuming
it.

### The wire does not need Wi-Fi

The wire trigger never touches the radio. A dead ESP32 or a missing access point leaves it working,
running the settings saved in NVM. The [demo trigger](#demo-trigger-over-wi-fi) is the opposite: it
is *only* the radio.

---

## Known limitations

1. **The wire is not commissioned yet.** No wire-triggered cue has run on real hardware. Demos use
   the [Wi-Fi demo trigger](#demo-trigger-over-wi-fi), which the apple pluck, perturb and maze configs
   enable.
2. **Only colour comes from ROS, and only over Wi-Fi.** Before a Wi-Fi cue, ROS sets its colour with
   `/config` (in RAM, never saved). Pattern, duration and brightness are always the board's settings,
   set from any machine joined to its access point.
3. **The wire has one appearance.** It carries one bit, so every wire-triggered cue is the configured
   cue. Per-event colours work over Wi-Fi only; giving the wire the same would need a second trigger
   line into another free pin, with the firmware holding one colour per line.
4. **`CUE_PIN = board.D2` is unverified on real hardware.** The tool-connector pinout comes from the
   KUKA media-flange manual, not from a measurement. Run the
   [commissioning checklist](../end_effector_design/README.md#commissioning-the-trigger--do-it-in-this-order)
   — continuity first, then the jumper test with `check_cue_wiring.py` — **before closing the
   effector casing**: polarity can be fixed over Wi-Fi afterwards, the pin choice cannot.
5. **Settings persistence depends on `microcontroller.nvm` being present in the build.** If it is
   absent, `/config?save=1` says so and settings revert to `DEFAULTS` on reset.
6. **No code upload over Wi-Fi.** Deliberate — see
   [Changing the firmware without USB](#changing-the-firmware-without-usb).
7. **No authentication or TLS on the HTTP path.** Acceptable only because the AP is isolated and
   WPA2-protected. Anyone on that AP can change the cue and read `code.py` (but not
   `settings.toml`). Do not put this board on a shared network as-is.
8. **`debug=True` on the HTTP server** prints every request to the serial console. Harmless, but
   noisy when you are watching for cue diagnostics.

---

## Provenance

`code.py` and `settings.toml` are original work for this project. Everything under `lib/` is from the
[Adafruit CircuitPython Bundle](https://github.com/adafruit/Adafruit_CircuitPython_Bundle) (MIT).

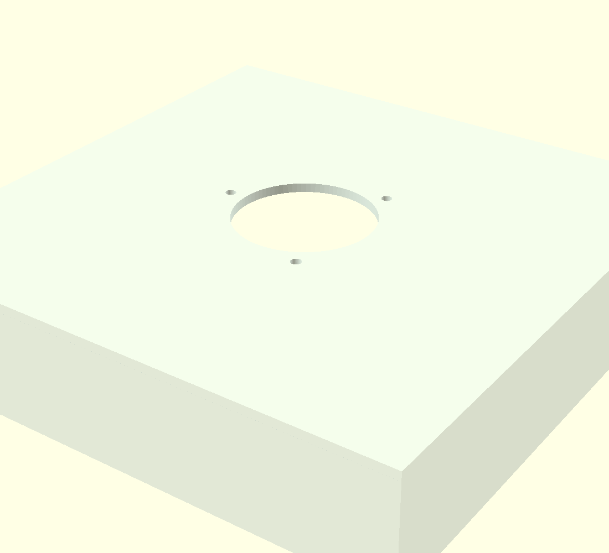
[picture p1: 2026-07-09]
end_effector_design/casing_box.png

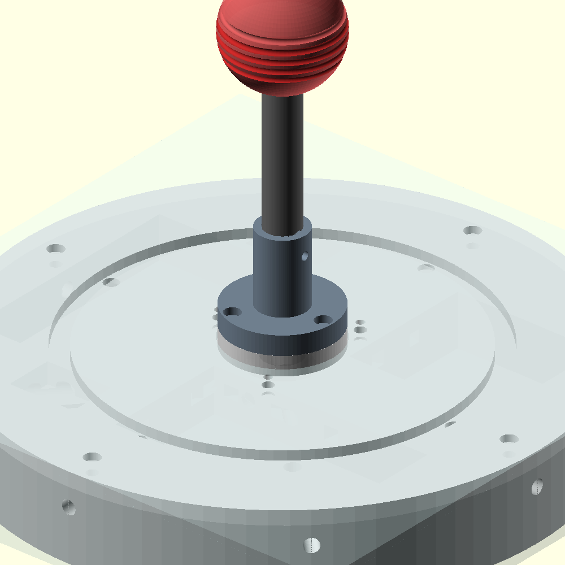
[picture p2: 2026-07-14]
end_effector_design/asm_final.png

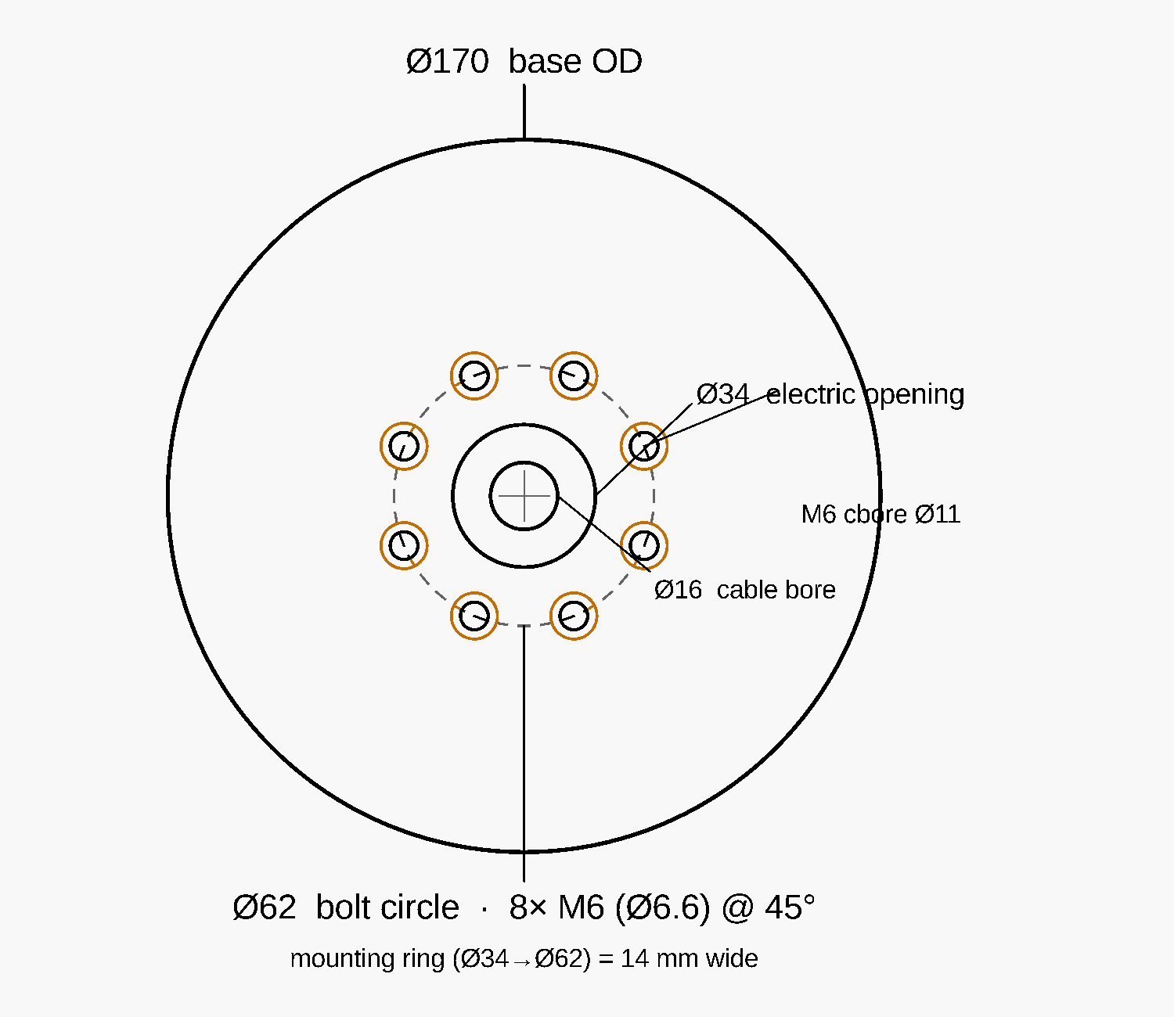
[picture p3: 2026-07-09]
end_effector_design/flange_dimensioned.png

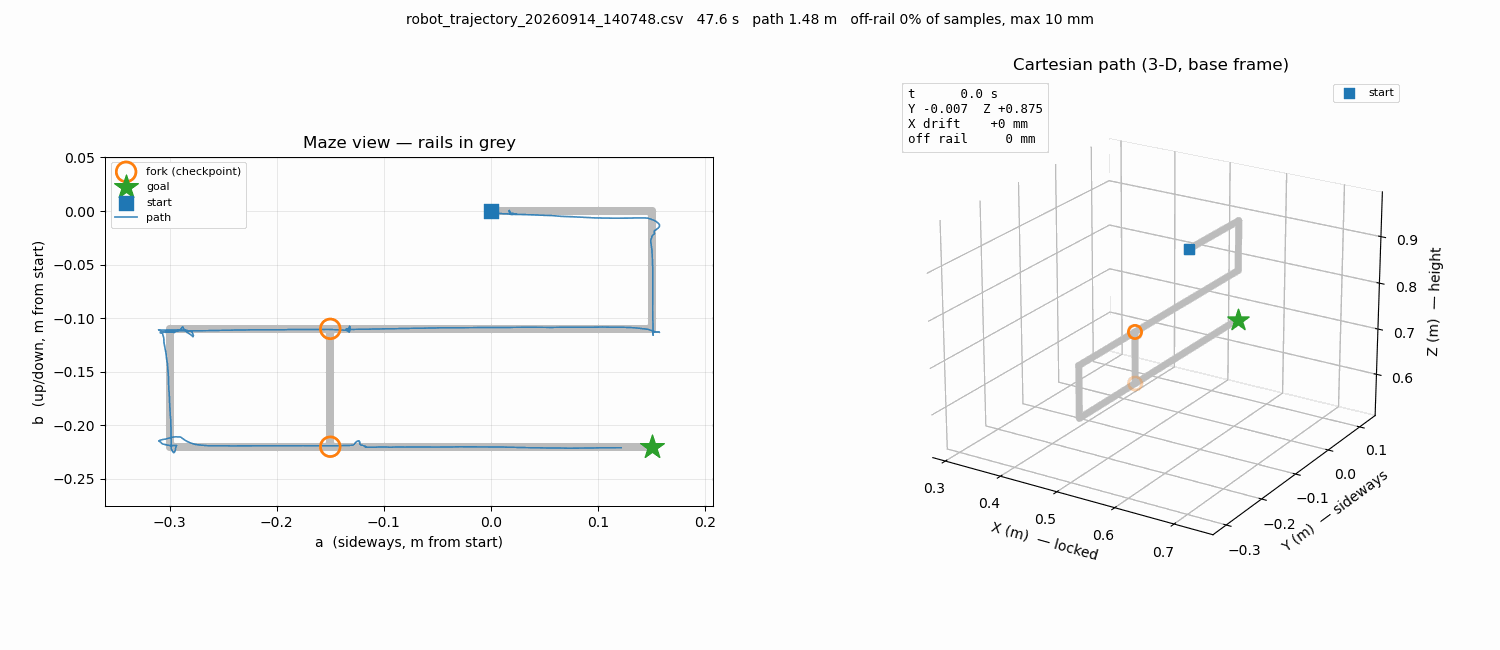
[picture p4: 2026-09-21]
analysis/maze_latest.gif

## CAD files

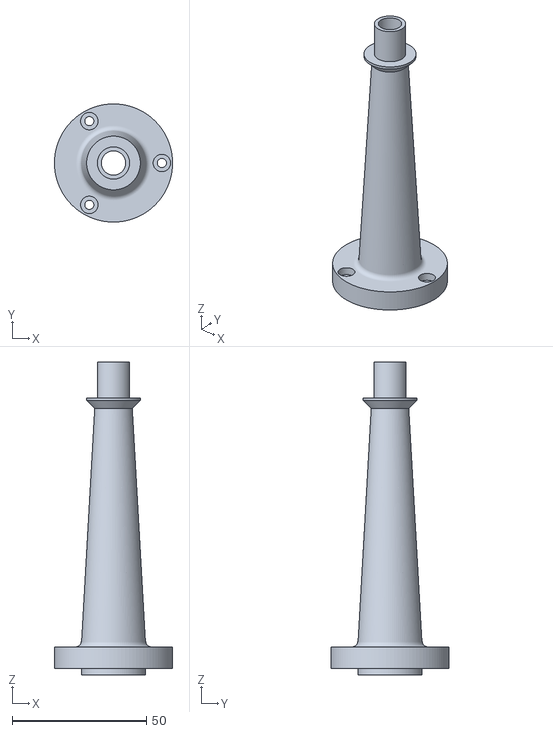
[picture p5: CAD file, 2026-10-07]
end_effector_design/apple_stem.stl
44.0 x 44.0 x 116.5

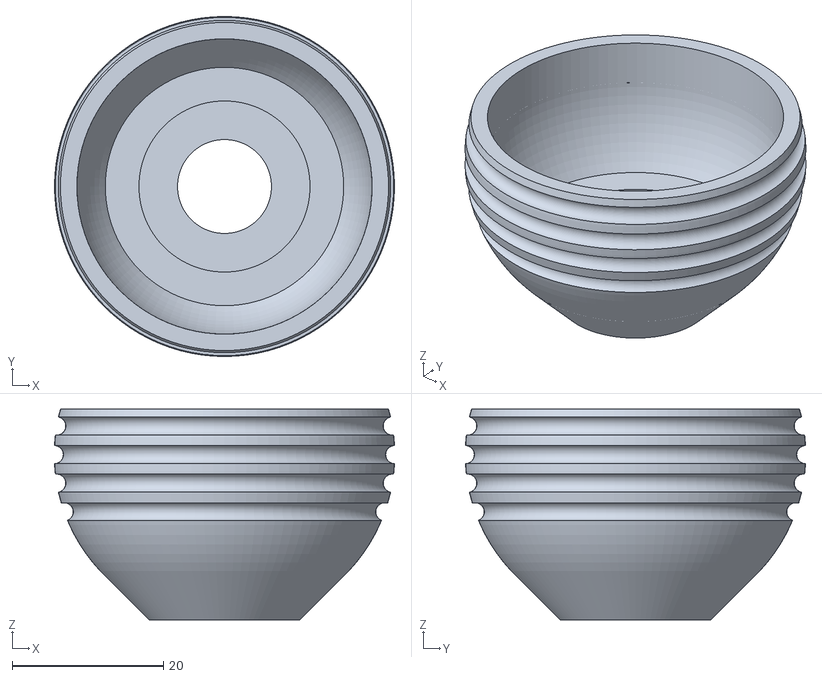
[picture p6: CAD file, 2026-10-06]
end_effector_design/apple_ball.stl
44.9 x 44.9 x 27.8

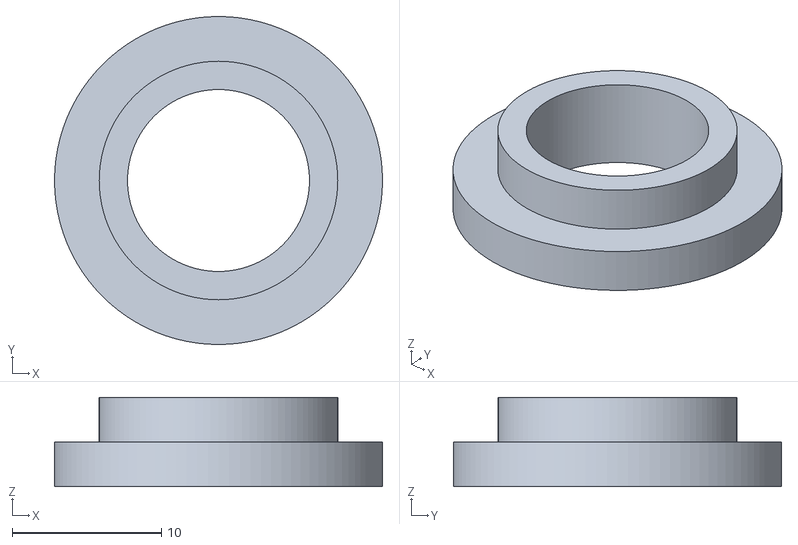
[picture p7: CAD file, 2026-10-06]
end_effector_design/apple_retainer.stl
22.0 x 22.0 x 6.00

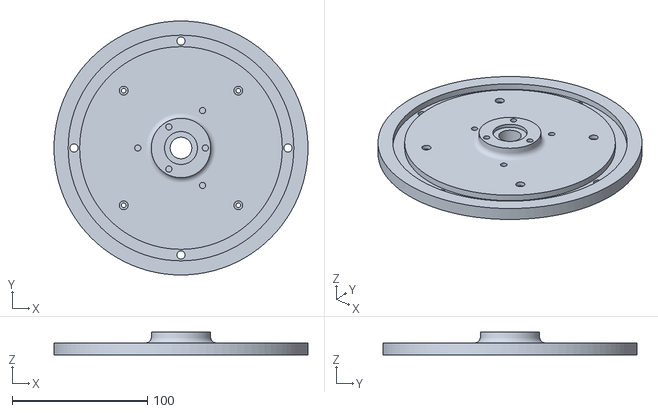
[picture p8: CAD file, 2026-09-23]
end_effector_design/cover.stl
188.0 x 188.0 x 17.0

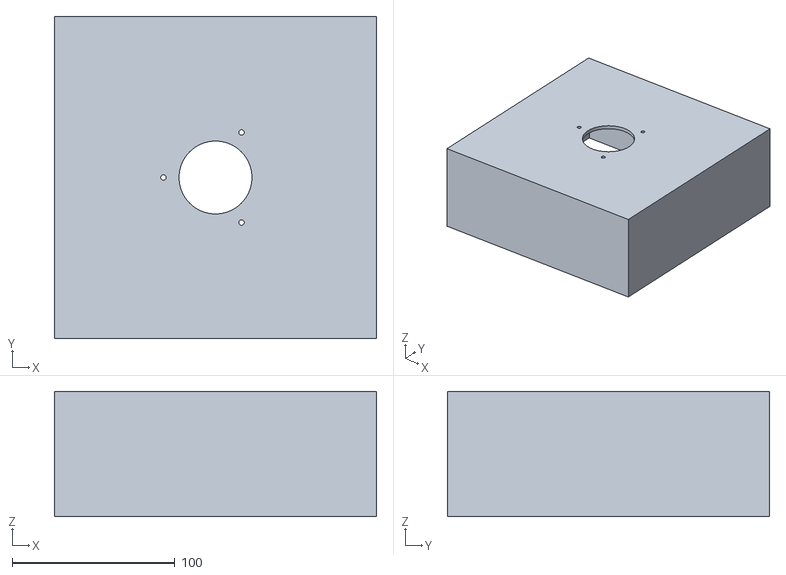
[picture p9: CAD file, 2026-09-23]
end_effector_design/casing.stl
198.0 x 198.0 x 77.0

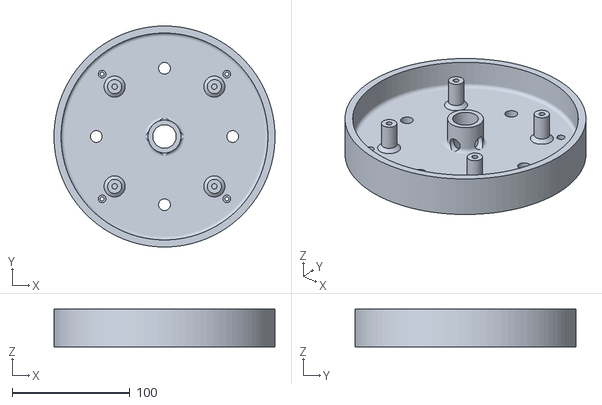
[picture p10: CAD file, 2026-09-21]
end_effector_design/base_tier2.stl
188.0 x 188.0 x 32.0

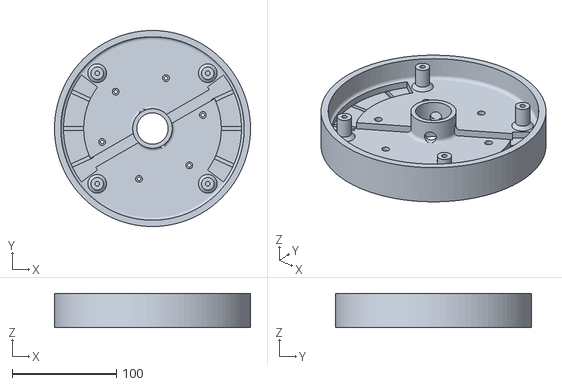
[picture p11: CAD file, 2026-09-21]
end_effector_design/base_tier1.stl
188.0 x 188.0 x 33.0

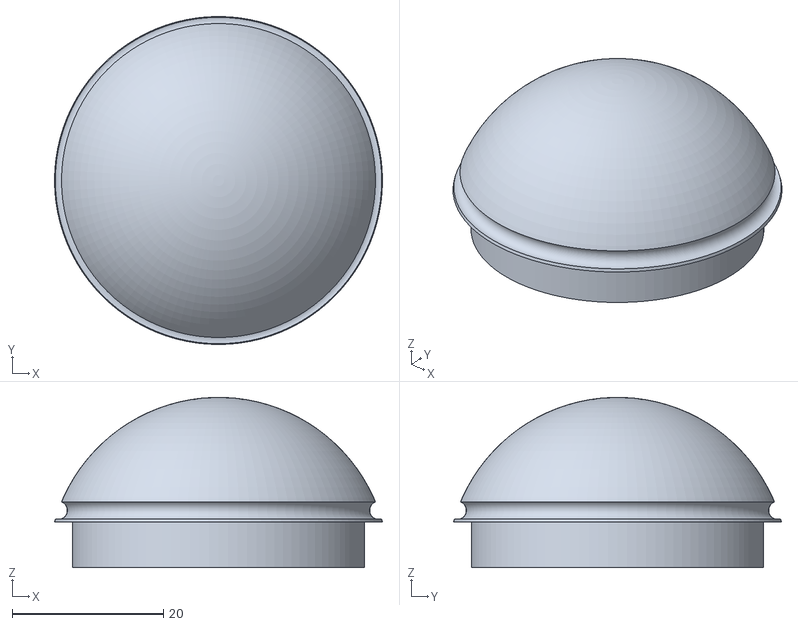
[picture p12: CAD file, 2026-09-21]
end_effector_design/apple_cap.stl
43.3 x 43.3 x 22.5

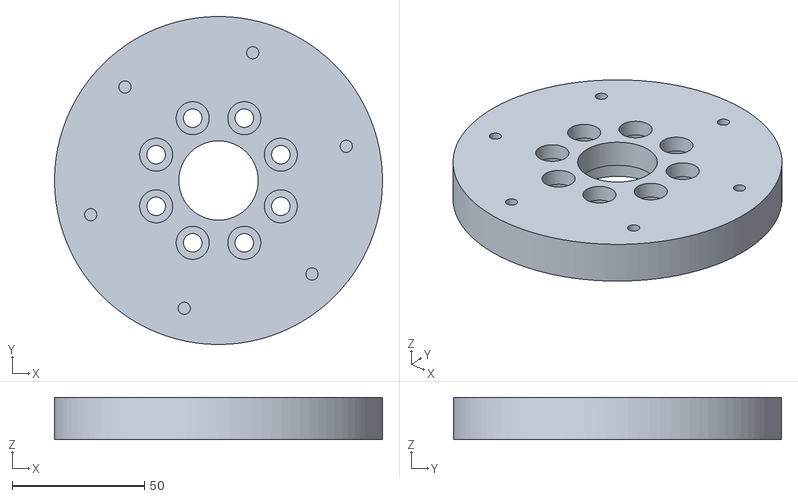
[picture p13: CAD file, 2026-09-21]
end_effector_design/flange_plate.stl
124.0 x 124.0 x 16.0

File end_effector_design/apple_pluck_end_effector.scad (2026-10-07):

// =====================================================================
//  Apple-pluck end-effector for the KUKA LBR iiwa7   (parametric)
//  sinthlab-kuka-stack / end_effector_design
//
//  ELECTRONICS HUB that bolts to the iiwa7 *media flange (electric)*, routes its
//  power/data wiring, drives a NeoPixel cue, and carries the control electronics.
//
//  The base is TWO STACKED TIERS sized by the ring groove + rim (Ø188), each ONE open compartment
//  with every board velcro'd and the wiring sunk below the floor. The apple is a PETG stem, a TPU
//  ball and cap, and a PETG retainer ring, printed apart. README.md has the full design notes; check_layout.py verifies the geometry.
//
//        [ iiwa7 media flange (electric) ]   8x M6 on a Ø51 pitch circle, 24V + data
//        (0) FLANGE PLATE  thick adapter disc: takes the 8x M6 (heads buried flush) + the Ø30 cable bore.
//                          Tier 1 bolts onto ITS top face with 6x M3 on a Ø100 circle.
//                 |  cable bundle THROUGH the Ø30 tier-1 centre
//        (1a) BASE TIER 1  Ø30 central bore (the flange bundle lands here) + PERIMETER CABLE TRENCH.
//              ├─ Metro M4 AirLift + power adapter   92 x 50   ALL VELCRO'D — no screw bosses.
//              ├─ RS-422 transceiver (MIKROE-2821)   45 x 28
//              └─ MPRLS pressure sensor              20 x 19
//        (1b) BASE TIER 2  stacks on tier 1 (4x M3); Ø20 bore — only ring/apple wiring goes higher.
//              ├─ Tobsun 24V->5V converter           70 x 65   <- tallest board, sets tier-2 height
//              ├─ Level shifter (ring data)          36 x 28
//              └─ DRV2605L haptic driver             28 x 20
//        (2) COVER       closes tier 2 · seats the NeoPixel ring in a groove on its TOP
//                        (opaque, same material as the base) · 4x M3 down into tier 2
//                 ▼ BOLTED FLANGE: apple STEM screws down into the cover (3x M3 + spigot)
//        (3) APPLE = (3a) STEM      ONE PETG part: cover flange + shaft + seat + tip
//                  + (3b) TPU BALL  sits on the seat; solid floor; OPEN top loads the ERM + sensor
//                  + (3c) RETAINER  PETG ring glued onto the tip, clamping the ball's floor
//                  + (3d) TPU CAP   press-fit dome that closes the ball; wires / FSR tail / tube exit the bore
//        ( + ) CLEAR CASING BOX   5-sided clear box (OPEN on the flange side) shrouding the whole
//                                  electronics stack; top covers the ring, clamps 3x M3 into the cover
//
//  Board layout is VERIFIED numerically by check_layout.py (no overlaps, every board corner inside the
//  compartment, every board clear of the tier bore and the pillars). Re-run it after ANY size change —
//  the tightest fit (the Tobsun) has 1.6 mm of margin.
//
//  !!!  VERIFY every flange/component dimension vs the real datasheets before printing.
//  Export one part at a time, e.g.:
//     openscad -D 'part="base_tier1"'  -o base_tier1.stl  apple_pluck_end_effector.scad
// =====================================================================

part = "assembly"; // [assembly, flange_plate, base_tier1, base_tier2, cover, apple_stem, apple_ball, apple_cap, apple_retainer, apple, apple_section, section, electronics_mock, casing]

/* [Robot media flange — MEASURED: 8x M6 on a Ø51 bolt circle, Ø34 central electric bore]
    THE ONE NUMBER THAT MUST MATCH THE ROBOT IS THE PITCH CIRCLE: 51 mm, centre-to-centre across two
    diametrically opposite holes (measured directly). Do NOT set it from an outer-edge span: that span is
    (pitch circle + hole Ø), and the plate's hole is deliberately BIGGER than the flange's, so the two
    spans differ by the clearance and are not comparable.

      on the ROBOT : pcd 51 + Ø6 tapped hole      -> outer-edge span 57  (what you measure on the arm)
      on the PLATE : pcd 51 + Ø7 clearance hole   -> outer-edge span 58  (0.5 mm of radial slop per side)
      plate TOP    : pcd 51 + Ø12.5 head well     -> outer-edge span 63.5 <-- NOT the bolt hole. This is
                     the counterbore the M6 cap head drops into, 10 mm above the mating face. Measuring
                     the plate from the top hits THIS, which is why it reads ~63.

    Derive the pitch circle from the flange's TAPPED holes (Ø6), never from the plate's clearance holes. */
flange_bolt_n      = 8;     // 8 x M6 fixing holes on the bolt circle
flange_pcd         = 51.0;  // bolt pitch-circle diameter [mm] — MEASURED centre-to-centre
flange_bolt_clear  = 7.0;   // M6 clearance hole, ISO 273 COARSE fit [mm]. Coarse on purpose: it absorbs
                            // the ±0.5 mm uncertainty in the measured pcd AND the fact that FDM holes
                            // print 0.2-0.4 mm undersize (a Ø6.6 hole prints ~6.3 and binds on an M6).
                            // The Ø12 steel washer under the head covers a Ø7 hole with room to spare.
flange_cbore_d     = 12.5;  // head-access well Ø for the M6 head [mm]. MEASURED head ~10; at Ø11 the well
                            // printed ~10.6 (FDM shrinks holes 0.2-0.4) and the head jammed part-way.
                            // Ø12.5 -> ~12.1 printed -> ~1 mm clearance/side, and clears a hex head's
                            // ~11.5 mm across-corners too. If your head is bigger, raise this (keep it
                            // below flange_washer_d so the washer still has a shoulder to seat on).
flange_mount_t     = 8.0;   // mounting-wall thickness under the M6 head [mm] — the bolt spans THIS (+ the
                            // washer) then threads into the flange, so a short M6x16 reaches (~6.4 mm bite).
flange_washer_d    = 14.0;  // washer-seat Ø under the head [mm] — clears a steel M6 flat washer (OD ~12)
                            // and stays > flange_cbore_d so its top edge is a shoulder that traps the washer
flange_washer_t    = 2.0;   // washer-seat depth [mm] (M6 washer ~1.6 thick); spreads bolt torque on the wall
flange_head_h      = 6.0;   // M6 cap-head height [mm] — buried in the plate so its top face stays flat
flange_first_angle = 22.5;  // first-hole angle [deg] — VERIFY clocking vs the flange
flange_center_d    = 34.0;  // central electric opening Ø [mm] ("inside electric"; clears the connector)
flange_center_h    = 6.0;   // opening/recess depth into the plate bottom [mm] — VERIFY connector protrusion

/* [(0) FLANGE PLATE — thick adapter disc: bolts to the robot, the base bolts onto IT]
    Split out of the base so the 8x M6 can be driven with the plate bare (heads recess flush into its top
    face), and so the printed base never carries the M6 clamp load. Assembly order: plate -> robot, base
    -> plate, THEN populate the electronics. */
plate_d        = 124;  // adapter plate Ø [mm]. The plate is what SUPPORTS tier 1's floor, and beyond
                       // its edge the floor is an unsupported cantilever out to r 94: Ø124 leaves
                       // 32 mm of overhang. A bigger plate shortens it further.
plate_t        = 16;   // plate thickness [mm] = mount wall 8 + washer seat 2 + M6 head 6 (head sits flush)
plate_screw_n  = 6;    // M3 screws holding tier 1 down onto the plate — six, evenly spread, because
                       // this joint carries the whole tool
plate_screw_bcd = 100; // their bolt-circle Ø [mm]. The joint reacts the apple's moment as a couple
                       // across this circle, so a wider circle is directly less force per screw. Still clear of the M6 washer seats (out to r 32.5), 12.8 mm
                       // inside the Ø124 plate rim, and clear of the nearest feed channel.
plate_screw_a0 = 15;   // first-screw angle [deg]. 15 threads the six between BOTH the feed channels
                       // at 30/210 (4.7 mm clear) and the tier-2 drops at 0/90/180/270 (16.2 mm), so
                       // nothing lands a wire on top of a screw head. (At a0=0 the drops at 0 and 180
                       // would come down 0.25 mm inside the screw well.)
plate_screw_depth = 6; // M3 insert bore depth into the plate top [mm] (takes a 4 mm insert)
plate_head_z   = 10;   // M3 head seat height above the tier-1 bottom [mm]: the thickness of printed
                       // material the head bears on, the critical section of the base<->flange joint.
                       // 10 mm below the head, 4 mm of well above. Takes M3x14 (10 through the floor
                       // + the full 4 mm insert, 2 mm short of the 6 mm hole's bottom). M3x16 bottoms out.
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

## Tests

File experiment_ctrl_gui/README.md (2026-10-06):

# Experiment Control Dashboard: architecture and software

**How to use the dashboard is in the main README:
[Quick start: the experiment dashboard](../README.md#quick-start-the-experiment-dashboard).** This file
covers how it is built: its components, the robot-side interfaces it relies on, how parameters are
classified, where the parameter help comes from, and how to extend it.

---

## Contents
- [Architecture](#architecture)
- [Components](#components)
- [Robot side: ExperimentControl](#robot-side-experimentcontrol)
- [Parameter model](#parameter-model)
- [Parameter documentation](#parameter-documentation)
- [HTTP API](#http-api)
- [Process control](#process-control)
- [Demo mode](#demo-mode)
- [Security](#security)
- [Extending](#extending)
- [Developing and testing](#developing-and-testing)

---

## Architecture

```mermaid
flowchart LR
    B["Browser<br/>static/index.html · app.js"]
    subgraph S["server.py (this folder)"]
        API["HTTP API + SSE<br/>log · state"]
        RUN["runner.py<br/>one ros2 launch"]
        BR["ros_bridge.py<br/>rclpy node"]
        PAR["params.py · experiments.py<br/>YAML → typed, tiered params"]
    end
    subgraph R["ROS 2 (namespace /lbr)"]
        L["ros2 launch sinthlab_bringup<br/>iiwa7_*.launch.py<br/>[params_file:=runs/…yaml]<br/>[clik_nullspace_cfg:=runs/…yaml]"]
        O["orchestrator<br/>+ ExperimentControl"]
        HW["lbr_state_broadcaster"]
    end
    Y[("sinthlab_bringup/config/*.yaml<br/>+ live_params.py")]

    B <-- "JSON · Server-Sent Events" --> API
    API --> RUN
    API --> BR
    API --> PAR
    PAR -. "reads" .-> Y
    RUN -- "subprocess (own process group)<br/>stdout → log" --> L
    L --> O
    O -- "experiment_status (JSON, latched)" --> BR
    BR -- "set_parameters_atomically (live only)" --> O
    BR -- "pause (SetBool)" --> O
    HW -- "lbr_state (FRI session, rate)" --> BR
```

- **The dashboard never talks to the arm.** It starts and stops the same `ros2 launch` a user would
  type, and uses the orchestrator's public ROS interfaces. The same interfaces serve the terminal
  (`ros2 param set`, `ros2 service call`), which is also why an experiment launched in a terminal
  is picked up automatically.
- **The YAMLs are the source of truth** for values, defaults, descriptions and notes. The dashboard
  never writes them: a per-run edit becomes a copy in `runs/`, passed as `params_file:=`.

---

## Components

| File | Role |
|---|---|
| `server.py` | `ThreadingHTTPServer`: static files, the JSON API, and a Server-Sent Events stream of log lines and state (state is re-sent every second). Owns start / stop / restart / stop-after-trial |
| `runner.py` | runs one `ros2 launch` in its own process group, pumps its output into the log ring buffer (5000 lines) and `logs/`, and stops it: SIGINT → 20 s → SIGTERM → 5 s → SIGKILL |
| `ros_bridge.py` | `RosBridge`: an rclpy node on a background executor that subscribes to `experiment_status` and `lbr_state` and calls `set_parameters_atomically` / `pause`. `UnavailableBridge` when ROS is not sourced. `DemoBridge` for `--demo` |
| `experiments.py` | the experiments (launch file, YAML, orchestrator node, SmartPad profile, controllers, run name, `group`): four experiments and three pre-training tasks, shown under the **Experiments** and **Pre-training** tabs (`GROUPS`); cautions and linked parameters |
| `params.py` | YAML → flat dotted names; descriptions and notes; type coercion; per-run edits; the edited YAML and CLIK posture files; the Fixed tab's sections |
| `static/` | the page: `index.html`, `style.css`, `app.js`. No external libraries or fonts |
| `demo_launch.py` | stands in for `ros2 launch` in demo mode |
| `check_param_docs.py` | fails if any key in `sinthlab_bringup/config/*.yaml` has no one-line description |
| `run_gui.sh` | sources ROS 2 and the workspace, then runs `server.py` |

Dependencies: the Python standard library and PyYAML (installed with ROS); `rclpy` and the message
packages when ROS is sourced.

---

## Robot side: ExperimentControl

[`helpers/experiment_control.py`](../sinthlab_bringup/sinthlab_bringup/helpers/experiment_control.py)
makes an orchestrator controllable from outside. Every orchestrator creates one:

| Interface | Type | Behaviour |
|---|---|---|
| `<ns>/experiment_status` | `std_msgs/String`, JSON, transient-local | published on every trial event and once a second: experiment, trial, phase, paused / held, live values **in effect**, and changes **pending** for the next trial |
| `<ns>/<orchestrator>/pause` | `std_srvs/SetBool` | `true`: finish this trial, recover, hold at the start. `false`: apply pending changes and start the next trial. A trial with no natural end (Free Move) registers `on_pause_request()` and ends its session at once on `true` |
| `set_parameters` | parameter callback | names in `live_params.py` are range-checked, accepted and **applied at the next trial boundary**; anything else is rejected with the reason |
| `on_event(token, arg)` | `TrialRecorder` hook | every `mark()` updates the status, and with `nsp_sync.enabled` sends the event's NSP code (`_pulse()`, a stub until the DIO arrives) |

The orchestrators end each trial with `control.begin_trial(self.start_trial)`. That call is where a
pause holds and where accepted changes are applied: `_reload_live()` calls `reload()` on the cue,
monitor and perturbation actions and resets the quiet-window and timeout durations. So a change
never lands mid-trial, and the sidecar written at the next `TrialRecorder.start()` records the
values that trial used.

---

## Parameter model

| Tier | Decided by | Enforced by |
|---|---|---|
| **Live** | `LIVE_PARAMS` in [`live_params.py`](../sinthlab_bringup/sinthlab_bringup/helpers/live_params.py): fnmatch globs per experiment | the orchestrator's parameter gate, and the server |
| **Per-run** | every other key in the experiment YAML | the server refuses edits while that experiment runs; the orchestrator rejects runtime sets |
| **Fixed** | not in the experiment YAML: SmartPad selections, launch arguments, `iiwa7_hardware_controllers.yaml`, the CLIK posture | shown read-only (`read_fixed_config()`) |

`live_params.py` has no ROS import, so the dashboard loads it from the source tree whether or not
ROS is sourced; the orchestrators import the same module, so the two cannot disagree. It also holds
the checks, which `check_value()` applies on both sides:
- `LIMITS` (ranges) and `CHOICES` (enums);
- **poses** (`check_pose`): 7 values, within `IIWA7_LIMITS_DEG`, and not a straight arm
  (max(|A2|, |A4|, |A6|) ≥ `STRAIGHT_BELOW_DEG`, 12° — the same test the Sunrise app uses for its
  ready-pose move);
- **pairs**, checked against the other values in force (`context`): the perturbation's r against its
  plane's cap (`PERTURB_R_MAX`), and the start pose against the recover pose, which must be equal.

Live motion parameters: the speed limits of every move are live in every experiment; the start /
recover pose is live in apple pluck and perturb only (`_POSE`). Each move action's `reload()` re-reads
them at the trial boundary, and Ruckig is rebuilt from them at the move's next start.

**Dashboard-only checks and conveniences** (`experiments.py`, `params.py`):
- `CAUTION`: amber notes on parameters other things depend on. They never lock anything.
- `LINKED`: `move_to_start.target_joint_position` and `move_to_start_recover.target_joint_position`
  are set together — per-run edits change both, and a live change sends both in one
  `set_parameters_atomically` call (all or nothing), so the node never sees them differ.
- **Parallel arrays** (`corridor_*`, `checkpoint_*`) must keep their length.
- **Coercion:** values from the browser are coerced to the YAML default's exact type, because ROS
  refuses a set that changes a parameter's type.

**Launch overrides** (`ExperimentParams.launch_overrides()`):
- With any edit, the YAML is written to `runs/<exp>_<time>.yaml` and passed as `params_file:=`.
- If a CLIK experiment's start pose was edited, a matching `runs/<exp>_<time>_clik_nullspace.yaml` is
  passed as `clik_nullspace_cfg:=`. `iiwa7_hardware.launch.py` joins that argument onto the package
  directory, and an absolute path replaces the package part, so the generated file is used as is.

---

## Parameter documentation

The help text comes from the YAML files (`params.yaml_docs()`):

```yaml
    # Notes: the reasoning, measurements, knobs. Comment lines directly above the key,
    # with no blank line between, belong to that key (or to that block, above a block).
    polar_r_m: 0.05  # perturbation distance from the start [m]      <- the description
```

- **Description:** the comment on the key's own line. It is shown under the parameter and at the top
  of its popup. Every key, blocks included, must have one.
- **Notes:** the comment block above the key. Prose lines are reflowed into paragraphs; indented
  lines (tables, diagrams) keep their columns.
- **Borrowed notes:** a key with no notes of its own borrows a sibling's notes when they mention it
  by name. The perturbation's notes sit above `polar_r_m` but explain θ and plane too.
- **Enforcement:** `check_param_docs.py` walks every YAML in `sinthlab_bringup/config/` and exits 1
  listing any undocumented key.

The Fixed tab's SmartPad and launch-argument rows are not YAML keys; their help is in
`SMARTPAD_HELP` and `LAUNCH_HELP` in `params.py`.

---

## HTTP API

POSTs need the header `X-Experiment-Ctrl: 1`; errors return 409 with `{"ok": false, "error": …}`.

| Method | Path | Does |
|---|---|---|
| GET | `/api/experiments` | every experiment, its tab (`group`) and its SmartPad selections |
| GET | `/api/groups` | the experiment-list tabs, in order: `experiments`, `pretraining` |
| GET | `/api/params/<exp>` | `params` (typed rows with tier, value, default, description, notes, caution, links, limits, choices), `groups` (block docs), `fixed` (Fixed tab sections) |
| GET | `/api/state` | runner state, ROS availability, status, robot, data folder, edit counts |
| GET | `/api/logs` | the log ring buffer |
| GET | `/api/events` | Server-Sent Events: `{"type": "log" \| "state", "data": …}` |
| POST | `/api/params/<exp>` `{name, value}` | per-run edit (linked keys follow); refused while that experiment runs |
| POST | `/api/params/<exp>/reset` | drop all edits |
| POST | `/api/start` `{experiment}` | launch; refused if anything is running, here or in a terminal |
| POST | `/api/stop` `{mode: "now" \| "after_trial"}` | Ctrl-C now, or pause and stop once the orchestrator reports it is holding |
| POST | `/api/restart` | stop now, then start the same experiment with the current edits |
| POST | `/api/pause` `{paused}` | the orchestrator's pause service |
| POST | `/api/live` `{name, value}` | `set_parameters_atomically` on the running orchestrator, with any linked parameter in the same call |
| POST | `/api/validate` | `analysis/validate_recording.py --folder <this run's folder>`, output to the log |

---

## Process control

- **Start:** `ros2 launch sinthlab_bringup <launch> [overrides]` runs with `start_new_session=True`,
  so one signal reaches the launch and every node it spawned. `RCUTILS_COLORIZED_OUTPUT=0` and
  `PYTHONUNBUFFERED=1` keep the log clean and live.
- **Stop now:** SIGINT to the process group, exactly like Ctrl-C. After 20 s it sends SIGTERM, and
  after 5 s more SIGKILL.
- **Stop after trial:** pause, then Stop now once the status reports `held`. For Free Move the pause
  itself ends the session, so the arm returns to the start first.
- **Restart:** Stop now; when the launch has exited, start again after 1 s.
- **Shutting down the server** stops a launch it started, the same way.
- **The data folder** is the newest `analysis/expt_<run_name>_*` modified since the launch started.

---

## Demo mode

`--demo` replaces the ROS side:
- `demo_launch.py` stands in for `ros2 launch`. It prints a banner and exits cleanly on SIGINT, so
  Start / Stop / Restart run for real.
- `DemoBridge` simulates an orchestrator on a fast clock. It uses the same trial phases, the same
  pause / held behaviour, the same live-parameter rules (`live_params.py`), the same apply-at-next-trial
  behaviour, and heartbeats once a second.

Nothing connects to the arm.

---

## Security

The server binds to `127.0.0.1` unless `--host` says otherwise, since whoever reaches it can start the
robot. POSTs require a custom header that a page on another site cannot send without CORS, which
the server never grants. So a malicious web page cannot drive the robot through a local browser.
Static files are served from `static/` only, with no path traversal.

---

## Extending

**A new live parameter:**
1. Add its name or glob to `LIVE_PARAMS` in `live_params.py`, with a range in `LIMITS` (and
   `CHOICES` if it is an enum).
2. Make the action that uses it re-readable: give it a `reload()` (see `AudioCue.reload()`,
   `CartesianImpedanceDisplacementMonitor.reload()`) and call that from the orchestrator's
   `_reload_live()`.
3. Declare it in the experiment YAML, with a one-line description on its line. ROS will not set a
   parameter the node never declared, and `check_param_docs.py` fails without the description.

It then appears on the Live tab automatically. Do step 2 before step 1: a listed name that is never
re-read would be accepted and silently ignored, which is the failure the gate exists to prevent.

**A new experiment:** add an `Experiment` to `EXPERIMENTS` in `experiments.py` (its `group` picks the
tab), an entry in
`LIVE_PARAMS`, and create an `ExperimentControl` in its orchestrator. The orchestrator must end each
trial with `control.begin_trial(...)` and pass `on_event=self.control.on_event` to its `TrialRecorder`.
Add its step list to `STEPS` in `static/app.js` for the status card.

---

## Developing and testing

```bash
python3 experiment_ctrl_gui/server.py --demo --port 8765      # the whole page against a simulated robot
python3 experiment_ctrl_gui/check_param_docs.py               # YAML documentation complete?
```

URL options, for testing and for linking:

| Option | Effect |
|---|---|
| `?exp=maze` | select an experiment |
| `?tab=live` \| `run` \| `fixed` | open a tab |
| `?hover=<parameter>` | open that parameter's help popup |
| `?nostream` | poll `/api/state` every second instead of using the event stream. Use it behind a proxy that breaks SSE, and for headless screenshots, since an open stream never lets a headless browser go idle |

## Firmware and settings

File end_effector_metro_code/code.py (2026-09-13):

# End-effector cue ring — Metro M4 AirLift (CircuitPython)
#
# Drives the 60-LED RGBW NeoPixel ring on the apple-pluck end effector.
#
# ---------------------------------------------------------------------------------------------
# HOW IT WORKS
# ---------------------------------------------------------------------------------------------
# TRIGGER (the wire).  Shorting X76 contacts 1-2 at the robot base pulls CUE_PIN to GND.
#                      The board runs its configured cue for its configured duration, then stops.
#                      On and off with a timer. That is the whole behaviour.
#                      No network is involved, so the trigger keeps working with Wi-Fi down.
#
# SETTINGS (the API).  The board hosts its OWN Wi-Fi access point. Join it from a laptop or phone
#                      and set what the cue looks like -- colour, brightness, pattern, segments,
#                      duration, rate -- with /config. `save=1` keeps it across reboots.
#
# The two are deliberately separate: the wire cannot carry a colour (it is one bit), and the
# experiment must never depend on a radio link. So the switch says WHEN, and the board -- already
# configured by hand -- decides WHAT.
#
# See README.md.

import os
import math
import time
import board
import busio
import struct
import neopixel
from digitalio import DigitalInOut, Direction, Pull
from adafruit_esp32spi import adafruit_esp32spi
import adafruit_esp32spi.adafruit_esp32spi_socketpool as socketpool
from adafruit_httpserver import Server, Request, Response

# ---------------------------------------------------------------------------
# Physical facts -- these describe the wiring, not a preference
# ---------------------------------------------------------------------------
ORDER = neopixel.GRBW
PHYSICAL_LEDS = 60
LED_PIN = board.D5              # -> Pixel Shifter (3.3 V -> 5 V) -> ring DIN
CUE_PIN = board.D2              # <- tool connector pin 9 (CTR1_1, via X76 contact 1)

# ---------------------------------------------------------------------------
# !!! POWER --- READ BEFORE RAISING `brightness` !!!
# ---------------------------------------------------------------------------
# `brightness` (0.0-1.0, set over /config) scales the ring's current draw very nearly linearly.
# It is NOT capped in firmware: you are responsible for keeping it inside what the hardware can
# actually deliver. At brightness = 1.0, 60 SK6812 RGBW LEDs draw roughly:
#
#     w=255 only            60 x ~20 mA  ~= 1.2 A     <- the white channel is the cheap one
#     r=g=b=255, w=0        60 x ~60 mA  ~= 3.6 A
#     r=g=b=w=255           60 x ~80 mA  ~= 4.8 A     <- absolute worst case
#
# Multiply by `brightness` for the actual draw. Before raising it, check ALL of:
#
#   * the Tobsun 24 V->5 V converter's current rating (and its derating when warm);
#   * the 5 V wiring gauge down the flange bore -- several amps through thin wire means
#     voltage drop, heat, and colour shift at the far end of the ring;
#   * that 5 V is injected at ALL FOUR quarter-ring joints. Feeding 60 LEDs through one arc's
#     traces browns out the far end and overheats the near end;
#   * the temperature inside the closed casing box. The effector is handled by an animal, so
#     surface temperature is a subject-safety limit, not just an electronics one;
#   * how bright a cue actually needs to be. A cue is a signal, not illumination -- the ring is
#     centimetres from the subject's face, so the lowest brightness that reads reliably is the
#     right one.
#
# NEVER feed the ring from the Metro's own 5 V pin: it comes off the board regulator and cannot
# source anything like these currents.
#
# The default of 0.2 is a deliberately conservative starting point (~0.24 A on the default
# white-channel cue), not a measured limit for your build.

FRAME_MS = 33                   # ~30 fps for the continuous patterns
CHASE_LEN = max(1, PHYSICAL_LEDS // 8)
PATTERNS = ("flash", "solid", "breathe", "chase", "segment")
MODES = ("pulse", "follow")
OFF = (0, 0, 0, 0)

# ---------------------------------------------------------------------------
# Settings -- the cue's appearance and the board's behaviour, in one place
# ---------------------------------------------------------------------------
# Every field is independent and settable over /config; send any subset and the rest is
# unchanged. This is the whole configurable surface of the board.
DEFAULTS = {
    # --- what the cue looks like ---
    "r": 0, "g": 0, "b": 0, "w": 255,   # colour; w is the dedicated white channel
    "pattern": "flash",                 # flash | solid | breathe | chase | segment
    "segments": 4,                      # lit blocks, for the "segment" pattern
    "duration": 2.0,                    # seconds the cue runs after a trigger
    "period": 0.5,                      # seconds per full cycle -> 2 Hz

    # --- how the board behaves ---
    "brightness": 0.2,                  # 0..1 -- scales the whole ring. READ THE POWER NOTE
                                        # ABOVE before raising this.
    "mode": "pulse",                    # pulse : the trigger starts a cue of `duration`
                                        # follow: the cue runs while the line is held
    "active_low": True,                 # shorting X76 1-2 pulls the pin to GND;
                                        # the pull-up then makes "idle" = HIGH, so an
                                        # unplugged connector reads as "no cue"
    "debounce_ms": 5,
    "retrigger": False,                 # True = a new edge restarts an in-flight cue
    "enabled": True,                    # False = ignore the wire entirely
}
cfg = dict(DEFAULTS)

# ---------------------------------------------------------------------------
# Pixels
# ---------------------------------------------------------------------------
# auto_write=False -> writes are buffered until an explicit pixels.show().
# pixel_order is the WIRE order; colours are always passed as (R, G, B, W).
pixels = neopixel.NeoPixel(
    LED_PIN, PHYSICAL_LEDS, brightness=cfg["brightness"],
    auto_write=False, pixel_order=ORDER,
)
pixels.fill(OFF)
pixels.show()

# Boot indicator: two short dim flashes, before anything that can fail or hang, so you can
# confirm from outside a closed effector that the board came up and the ring is wired.
for _ in range(2):
    pixels.fill((0, 0, 0, 40))
    pixels.show()
    time.sleep(0.12)
    pixels.fill(OFF)
    pixels.show()
    time.sleep(0.12)

# ---------------------------------------------------------------------------
# Persistence -- microcontroller.nvm
# ---------------------------------------------------------------------------
# NVM is used INSTEAD of a config file because writing to the filesystem would require
# storage.remount() in boot.py, which makes CIRCUITPY read-only to the host computer -- see
# README. NVM has neither that cost nor that risk. Not every build exposes it, so every access
# is guarded: without NVM the board still works, settings just revert to defaults on reset.
_NVM_MAGIC = 0xC9
_NVM_VER = 5
_NVM_FMT = "<BB" "BBBB" "BBBB" "HHB"
# magic, ver | r, g, b, w | brightness, flags, debounce, segments | dur_cs, per_cs, pattern
# The round trip quantises: brightness is one byte (~0.4% steps) and duration/period are
# centiseconds (10 ms steps). Far finer than anything that matters here, but a value read back
# after a save will not be bit-identical to what you sent.
_NVM_LEN = struct.calcsize(_NVM_FMT) + 1        # +1 checksum

nvm_writes = 0                  # actual flash writes this power-up; reported by /status so a
                                # script that saves too eagerly is visible rather than silent

# microcontroller.nvm is present on this board (confirmed: /status reports nvm=available), and on
# every current CircuitPython build for it. The fallback below is NOT hedging about that -- it is
# there because this runs at MODULE SCOPE, before the trigger is set up. If `nvm` were ever None,
# an unguarded `_nvm[0:16]` would raise here and code.py would stop before poll_trigger() exists,
# so the board would fire no cue at all. Falling back to a RAM buffer costs two lines and means
# the save/load functions below have no conditionals in them at all: they always work, and the
# only difference is whether the values outlive a reboot.
try:
    import microcontroller
    _nvm = microcontroller.nvm
    _nvm_is_flash = _nvm is not None and len(_nvm) >= _NVM_LEN
except Exception:
    _nvm_is_flash = False
if not _nvm_is_flash:
    _nvm = bytearray(_NVM_LEN)  # settings still work; they just do not survive a power cycle


def _nvm_pack():
    flags = ((1 if cfg["enabled"] else 0)
             | (2 if cfg["active_low"] else 0)
             | (4 if cfg["retrigger"] else 0)
             | (8 if cfg["mode"] == "follow" else 0))
    blob = struct.pack(
        _NVM_FMT, _NVM_MAGIC, _NVM_VER,
        cfg["r"], cfg["g"], cfg["b"], cfg["w"],
        int(cfg["brightness"] * 255), flags, cfg["debounce_ms"], cfg["segments"],
        min(int(cfg["duration"] * 100), 65535), min(int(cfg["period"] * 100), 65535),
        PATTERNS.index(cfg["pattern"]),
    )
    return blob + bytes([sum(blob) & 0xFF])


def nvm_save():
    """Persist the settings.

    A write to microcontroller.nvm is an erase+program of a flash row, and the SAMD51's flash is
    rated for a finite number of those (~25k cycles; check your datasheet). Two things keep that
    a non-issue:

      * saving is NEVER automatic -- this is called only from /config?save=1;
      * an identical save costs nothing. Re-saving the same settings, or a script that calls
        save=1 in a loop, compares equal here and returns without touching flash.

    So the cycle count only advances when the stored settings actually change.
    """
    global nvm_writes
    blob = _nvm_pack()
    if bytes(_nvm[0:_NVM_LEN]) == blob:
        return True                     # already stored -- no erase, no wear
    _nvm[0:_NVM_LEN] = blob
    nvm_writes += 1
    return True


def nvm_load():
    """Overlay the saved settings onto cfg. True only if a valid record was found."""
    blob = bytes(_nvm[0:_NVM_LEN])
    if blob[0] != _NVM_MAGIC or blob[1] != _NVM_VER:
        return False
    if (sum(blob[:-1]) & 0xFF) != blob[-1]:
        return False
    (_, _, r, g, b, w, bright, flags, deb, seg,
     dur, per, pat) = struct.unpack(_NVM_FMT, blob[:-1])
    if pat >= len(PATTERNS):
        return False                    # reject the WHOLE record rather than load half of it
    cfg.update({
        "r": r, "g": g, "b": b, "w": w,
        "brightness": min(bright / 255.0, 1.0),
        "pattern": PATTERNS[pat], "segments": max(1, min(seg, PHYSICAL_LEDS // 2)),
        "duration": max(dur / 100.0, 0.05), "period": max(per / 100.0, 0.02),
        "debounce_ms": max(deb, 1),
        "enabled": bool(flags & 1), "active_low": bool(flags & 2),
        "retrigger": bool(flags & 4), "mode": "follow" if flags & 8 else "pulse",
    })
    return True


def nvm_clear():
    global nvm_writes
    if _nvm[0] == 0:
        return True                     # already invalid -- do not wear flash to re-zero it
    _nvm[0:1] = b"\x00"                 # wiping the magic byte invalidates the record
    nvm_writes += 1
    return True


_nvm_loaded = nvm_load()
pixels.brightness = cfg["brightness"]

# ---------------------------------------------------------------------------
# Cue engine -- non-blocking
# ---------------------------------------------------------------------------
# Driven from the main loop by cue_service(); no handler ever sleeps. That is what lets a cue
# animate while the HTTP server stays responsive, and why the wire trigger's latency is the
# debounce time regardless of network traffic.
_cue_until_ns = 0                       # 0 = idle; -1 = run until stopped ("follow" mode)
_cue_start_ns = 0
_cue_period_ns = 1
_cue_color = OFF
_cue_pattern = "flash"
_cue_segments = 4
_cue_frame_ns = 0
_cue_step = -1
_cue_restore = None                     # ring contents to put back when the cue ends


def cue_active():
    return _cue_until_ns != 0


def _snapshot():
    return [pixels[i] for i in range(PHYSICAL_LEDS)]


def _restore(snap):
    for i in range(PHYSICAL_LEDS):
        pixels[i] = snap[i]
    pixels.show()


def _scaled(c, k):
    return (int(c[0] * k), int(c[1] * k), int(c[2] * k), int(c[3] * k))


def _render(phase):
    """Draw one frame. phase is 0.0-1.0 through the current cycle."""
    if _cue_pattern == "solid":
        pixels.fill(_cue_color)
    elif _cue_pattern == "breathe":
        # Starts at FULL and dips, rather than starting dark and fading up. A cue has to be
        # visible the instant it fires; a rise-first breathe would delay perceived onset by half
        # a period (0.6 s at the default rate), which is exactly the thing the wire is precise
        # about. Every pattern is lit at phase 0 for the same reason.
        pixels.fill(_scaled(_cue_color, 0.5 + 0.5 * math.cos(2 * math.pi * phase)))
    elif _cue_pattern == "chase":
        pixels.fill(OFF)
        head = int(phase * PHYSICAL_LEDS)
        for i in range(CHASE_LEN):
            pixels[(head + i) % PHYSICAL_LEDS] = _cue_color
    elif _cue_pattern == "segment":
        # N lit blocks evenly spaced around the ring, flashing together. Visually distinct from
        # a full-ring flash at a glance, which is the point of having it at all.
        pixels.fill(OFF)
        if phase < 0.5:
            n = max(1, _cue_segments)
            block = max(1, PHYSICAL_LEDS // (2 * n))
            for k in range(n):
                start = (k * PHYSICAL_LEDS) // n
                for j in range(block):
                    pixels[(start + j) % PHYSICAL_LEDS] = _cue_color
    else:                                       # "flash"
        pixels.fill(_cue_color if phase < 0.5 else OFF)
    pixels.show()


def cue_start(spec, follow=False):
    """Run a cue spec. follow=True means 'until cue_stop()', ignoring the spec's duration."""
    global _cue_until_ns, _cue_start_ns, _cue_period_ns, _cue_color
    global _cue_pattern, _cue_segments, _cue_frame_ns, _cue_step, _cue_restore
    led_test_stop()                     # a cue always wins over the LED test; stopping it first
                                        # also keeps a test frame out of the snapshot below
    now = time.monotonic_ns()
    if not cue_active():
        _cue_restore = _snapshot()      # snapshot the pre-cue ring, never a cue frame
    # The colour is used exactly as set. Scaling happens once, in pixels.brightness, so the
    # values you configure are the values that come back from /status -- no rounding surprises.
    _cue_color = (spec["r"], spec["g"], spec["b"], spec["w"])
    _cue_segments = max(1, min(int(spec["segments"]), PHYSICAL_LEDS // 2))
    _cue_pattern = spec["pattern"] if spec["pattern"] in PATTERNS else "flash"
    _cue_period_ns = max(int(spec["period"] * 1_000_000_000), 20_000_000)    # floor 20 ms
    _cue_until_ns = -1 if follow else now + int(max(spec["duration"], 0.01) * 1_000_000_000)
    _cue_start_ns = now
    _cue_frame_ns = now
    _cue_step = 0
    _render(0.0)


def cue_stop(restore=True):
    global _cue_until_ns, _cue_restore, _cue_step
    if not cue_active():
        return
    _cue_until_ns = 0
    _cue_step = -1
    if restore and _cue_restore is not None:
        _restore(_cue_restore)
    _cue_restore = None


def cue_service():
    """Advance the animation. Call every pass of the main loop."""
    global _cue_frame_ns, _cue_step
    if not cue_active():
        return
    now = time.monotonic_ns()
    if _cue_until_ns > 0 and now >= _cue_until_ns:
        cue_stop()
        return
    if _cue_pattern == "solid":
        return                                  # nothing to animate
    phase = ((now - _cue_start_ns) % _cue_period_ns) / _cue_period_ns
    if _cue_pattern == "flash" or _cue_pattern == "segment":
        step = 0 if phase < 0.5 else 1          # two states -- redraw on the boundary only
        if step == _cue_step:
            return
        _cue_step = step
    else:                                       # breathe / chase -- fixed frame rate
        if now - _cue_frame_ns < FRAME_MS * 1_000_000:
            return
        _cue_frame_ns = now
    _render(phase)


# ---------------------------------------------------------------------------
# LED test -- walk every pixel through red, green, blue, white   (/led_test)
# ---------------------------------------------------------------------------
# One pixel lit at a time, each colour held for `step` seconds, everything else dark. It is the
# right tool for a ring that is partly dark, for two reasons:
#
#   * it draws ONE LED's current, so a pixel that stays dark here is not the supply sagging under
#     load -- it is a data joint, a dead LED, or an arc with no 5 V/GND of its own;
#   * /status reports led_test_pixel while it runs, so the index where the ring goes dark is a
#     number you read, not a count you make by eye.
#
# Non-blocking like the cue engine: led_test_service() steps it from the main loop. Anything else
# that drives the ring -- a cue, /off, /set_color, /segments -- stops it.
LED_TEST_COLOURS = (("red", (255, 0, 0, 0)), ("green", (0, 255, 0, 0)),
                    ("blue", (0, 0, 255, 0)), ("white", (0, 0, 0, 255)))
_lt_pixel = -1                          # -1 = idle
_lt_colour = 0                          # index into LED_TEST_COLOURS
_lt_first = 0
_lt_last = PHYSICAL_LEDS - 1
_lt_step_ns = 250_000_000
_lt_next_ns = 0
_lt_loop = False


def led_test_active():
    return _lt_pixel >= 0


def _lt_draw():
    pixels.fill(OFF)
    pixels[_lt_pixel] = LED_TEST_COLOURS[_lt_colour][1]
    pixels.show()
    print("led_test: pixel {} {}".format(_lt_pixel, LED_TEST_COLOURS[_lt_colour][0]))


def led_test_start(first, last, step_s, loop):
    global _lt_pixel, _lt_colour, _lt_first, _lt_last, _lt_step_ns, _lt_next_ns, _lt_loop
    cue_stop(restore=False)
    _lt_first, _lt_last, _lt_loop = first, last, loop
    _lt_step_ns = int(step_s * 1_000_000_000)
    _lt_pixel, _lt_colour = first, 0
    _lt_next_ns = time.monotonic_ns() + _lt_step_ns
    _lt_draw()


def led_test_stop(clear=True):
    global _lt_pixel
    if _lt_pixel < 0:
        return
    _lt_pixel = -1
    if clear:
        pixels.fill(OFF)
        pixels.show()


def led_test_service():
    """Advance the LED test. Call every pass of the main loop."""
    global _lt_pixel, _lt_colour, _lt_next_ns
    if _lt_pixel < 0:
        return
    now = time.monotonic_ns()
    if now < _lt_next_ns:
        return
    _lt_next_ns = now + _lt_step_ns     # timed from now: a slow pass cannot queue a burst of steps
    _lt_colour += 1
    if _lt_colour == len(LED_TEST_COLOURS):
        _lt_colour = 0
        _lt_pixel += 1
        if _lt_pixel > _lt_last:
            if not _lt_loop:
                led_test_stop()
                print("led_test: done")
                return
            _lt_pixel = _lt_first
    _lt_draw()


# ---------------------------------------------------------------------------
# Hardwired trigger -- debounced edge detection
# ---------------------------------------------------------------------------
cue_in = DigitalInOut(CUE_PIN)
cue_in.direction = Direction.INPUT

_trig_state = False                     # debounced logical level ("asserted")
_trig_raw = False
_trig_since_ns = 0
fired = 0                               # wire-triggered cue count, echoed by /status


def trigger_asserted():
    return (not cue_in.value) if cfg["active_low"] else cue_in.value


def apply_polarity():
    """(Re)configure the input pull and resync the debouncer.

    Called at boot and whenever active_low changes over HTTP -- resyncing matters, otherwise
    flipping the polarity would look like an edge and fire a spurious cue.
    """
    global _trig_state, _trig_raw, _trig_since_ns
    cue_in.pull = Pull.UP if cfg["active_low"] else Pull.DOWN
    _trig_state = _trig_raw = trigger_asserted()
    _trig_since_ns = time.monotonic_ns()


def poll_trigger():
    global _trig_state, _trig_raw, _trig_since_ns, fired
    raw = trigger_asserted()
    now = time.monotonic_ns()

    if raw != _trig_raw:                        # level changed -- restart the debounce window
        _trig_raw = raw
        _trig_since_ns = now
        return
    if raw == _trig_state:
        return
    if now - _trig_since_ns < cfg["debounce_ms"] * 1_000_000:
        return

    _trig_state = raw                           # debounced edge
    if not cfg["enabled"]:
        return
    if raw:
        follow = cfg["mode"] == "follow"
        if follow or cfg["retrigger"] or not cue_active():
            fired += 1
            cue_start(cfg, follow=follow)       # on, then off after `duration`. That is all the
                                                # wire does -- it carries no colour, only timing.
    elif cfg["mode"] == "follow":
        cue_stop()


apply_polarity()
print("Cue input on {} (active {}), mode={}, nvm={}".format(
    CUE_PIN, "low" if cfg["active_low"] else "high", cfg["mode"],
    "restored" if _nvm_loaded else ("available" if _nvm else "UNAVAILABLE")))

# ---------------------------------------------------------------------------
# HTTP route handlers
# ---------------------------------------------------------------------------
# Defined unconditionally, registered further down only if the Wi-Fi stack came up. Nothing
# here sleeps -- every handler returns immediately and lets the main loop do the animation.

def _int(request, name, default, lo=0, hi=255):
    """Query param as int, clamped. Bad input falls back to the default, never raises."""
    try:
        return min(hi, max(lo, int(request.query_params.get(name, default))))
    except (TypeError, ValueError):
        return default
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

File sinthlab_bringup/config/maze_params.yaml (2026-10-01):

/**:
  ros__parameters:
    # Maze runs in POSITION mode: move_to_start/recover use MoveToPositionJointSpace, and MoveInMazeAction
    # streams the rail-constrained equilibrium to kuka_clik_controller. The CABINET
    # (LbrImpedanceControlServer) provides the compliance and holds the arm to the rails.
    #
    # >>> USE THE "Maze walls + easy guiding (rot 120)" SmartPad profile.
    # It is anisotropic {2500, 1000, 1000, 120, 120, 120}. X 2500 locks the radial axis so the plane is
    # enforced in hardware; Y/Z 1000 hold the arm firmly on the rails; rot 120 is the knob that makes
    # guiding light. No uniform profile works: 400 gives walls too weak to feel (4 N/cm), and at 3000
    # tracking lag dominates.
    #
    # Sister profiles differ ONLY in rotational stiffness: "Maze walls (X lock, Y/Z firm)" rot 300,
    # "... light guiding (rot 60)" and "... very light guiding (rot 30)". Go lower if guiding feels heavy
    # even when moving slowly; go higher if the tool twists more than the experiment allows. Rotational stiffness defines NOTHING
    # about the maze (its constraints are all translational), but holding orientation while translating
    # is the expensive motion, so it is the one lever that reduces effort without softening the plane
    # or the rails.
    #
    # Tracking lag is a separate lever: the raised clamps (kuka_clik_controller.max_linear_velocity +
    # max_target_step_m below) are what stop the rails feeling heavy when you move fast.
    #
    # GEOMETRY IS SOLVED, NOT GUESSED. Every position below is in metres, base frame (lbr_link_0), and
    # was checked by IK against the real iiwa7 URDF: the start posture points the tool axis (the EE
    # frame's Z axis, the approach direction) along +X to within ~11 deg, and all corridor corners are
    # reachable while HOLDING that orientation (the fixture locks orientation, so a corner the arm can
    # only reach by twisting the tool is unusable).
    #
    # NOTE the EE frame's other axes are NOT aligned with the base: local X is ~22 deg off straight
    # DOWN and local Y is ~base +Y. Only local Z (the tool/approach axis) is the ~+X one -- read the
    # third column of the EE transform, not the first, when checking where the tool points.
    #
    # The horizontal-tool pose costs reach: holding the tool along +X, the arm can only work in
    #   X in [0.50, 0.75], Y in [-0.25, +0.25]  at z = 0.50
    # (below X~0.50 the wrist folds back and the pose becomes unreachable). The whole maze lives inside
    # that box with margin. If you move the maze, re-run the reach check before trusting it.
    state_topic: "lbr_state"  # LBRState topic, relative to the robot namespace
    base_link: "lbr_link_0"  # URDF base link the fixture works in
    end_effector_link: "lbr_link_ee"  # URDF end-effector link the fixture constrains

    # Whole-experiment timeout [s]; on expiry the arm waits for release then returns to start.
    timeout_sec: 60.0  # trial time limit [s]; on expiry: timeout cue, wait for release, reset

    # A straight (singular) arm -- mechanical zero, or near it -- never reaches this experiment: the
    # Sunrise app (LbrImpedanceControlServer) PTPs it to a ready pose in position control before ROS
    # connects, and the maze start is reachable from there.
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

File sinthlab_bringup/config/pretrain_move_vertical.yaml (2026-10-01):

/**:
  ros__parameters:
    # PRE-TRAINING: MOVE VERTICAL. One straight vertical rail through the start -- one leg of the maze.
    # The arm can only slide up and down it. Moving it travel_task.threshold_m away from the start turns
    # the travel quarters of the ring from GREEN to RED; bringing it back to the start ends the trial
    # with the reward. Same start pose, plane and SmartPad setup as the maze, so it leads straight into it.
    #
    # >>> SmartPad: "Maze walls + easy guiding (rot 120)" (or a lighter-rot sister), damping 0.7, elbow 30
    # -- exactly the maze's setup. X 2500 holds the plane; Y 1000 holds the arm on the rail.
    #
    # REACH, from this start holding the tool orientation (optas IK on the iiwa7 URDF): down is easy (at
    # -0.25 m every joint is still >= 11 deg from its limit); UP is the limit -- the arm nears a singular
    # pose above +0.12 m (smallest singular value 0.11 at +0.12, 0.07 at +0.15) and +0.20 m is unreachable.
    # Hence a rail of +/-0.12 m and a 0.10 m threshold.
    #
    # GRAVITY: along a free vertical rail nothing holds the arm up except the load-data gravity model.
    # The residual (~5 N down at the tool) lets an untouched arm sink a few cm and stop. The rail anchors
    # after that settle (anchor_settle_sec), and the threshold must stay well beyond what it sinks on its
    # own -- check that on the arm before a monkey session (an untouched arm must not reach it).
    experiment: "move_vertical"  # experiment name in the status topic, the trial data and the dashboard
    state_topic: "lbr_state"  # LBRState topic, relative to the robot namespace
    base_link: "lbr_link_0"  # URDF base link the rail is defined in
    end_effector_link: "lbr_link_ee"  # URDF end-effector link the rail constrains

    timeout_sec: 30.0  # trial time limit [s]; on expiry: timeout cue, wait for release, reset

    move_to_start:  # joint-space move to the trial start pose (the maze start)
      update_rate: 200  # loop rate of this action [Hz]
      # The maze start: EE ~ (0.50, 0.00, 0.90) m, tool along +X toward the subject. Keep equal to
      # move_to_start_recover and to nullspace_desired_configuration in config/clik_nullspace_maze.yaml.
      target_joint_position: [-3.6, 69.9, -3.6, 70.0, 0.7, 79.5, -15.7]  # start pose, joint angles A1..A7 [deg]
      joint_move_tolerance: 0.03  # done when every joint is within this of its target [rad]
      wait_for_physical_arrival: true  # also wait for the MEASURED arm to arrive: the rail anchors on it
      cartesian_move_tolerance: 0.03  # EE within this of the target counts as physically arrived [m]
      move_to_pos_v_max: [40.0, 40.0, 40.0, 40.0, 40.0, 40.0, 40.0]  # peak joint speed [deg/s]
      move_to_pos_a_max: 2.0  # joint acceleration limit [rad/s^2]
      move_to_pos_j_max: 5.0  # joint jerk limit [rad/s^3]
      debug_log_enabled: false  # print this action's periodic debug line
      debug_log_rate_hz: 2.0  # how often that debug line prints [Hz]
    move_to_start_recover:  # joint-space move back to the start at the end of each trial
      update_rate: 200  # loop rate of this action [Hz]
      target_joint_position: [-3.6, 69.9, -3.6, 70.0, 0.7, 79.5, -15.7]  # recover pose A1..A7 [deg], same as move_to_start
      joint_move_tolerance: 0.15  # done when every joint is within this of its target [rad]
      wait_for_physical_arrival: true  # also wait for the MEASURED arm to arrive, not just the command
      cartesian_move_tolerance: 0.05  # EE within this of the target counts as physically arrived [m]
      move_to_pos_v_max: [40.0, 40.0, 40.0, 40.0, 40.0, 40.0, 40.0]  # peak joint speed, per joint [deg/s]
      move_to_pos_a_max: 2.0  # joint acceleration limit [rad/s^2]
      move_to_pos_j_max: 5.0  # joint jerk limit [rad/s^3]
      debug_log_enabled: false  # print this action's periodic debug line
      debug_log_rate_hz: 2.0  # how often that debug line prints [Hz]

    # ---- THE TASK (live: change between trials from the dashboard) ----
    travel_task:  # out to the threshold, then back to the start
      update_rate: 50  # loop rate of this monitor [Hz]
      axis: "z"  # which base axis counts as travel: z = up/down (per-run; the rail decides it)
      threshold_m: 0.10  # travel from the start that turns the ring red [m]; must be short of the rail end
      direction: "both"  # which way counts: both | positive (up) | negative (down)
      require_return: true  # true: the trial succeeds back at the start; false: at the threshold
      return_tolerance_m: 0.02  # "back at the start" = within this of it [m]
      debug_log_enabled: false  # print the travel periodically
      debug_log_rate_hz: 2.0  # how often that line prints [Hz]
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

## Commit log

2025-09-16 adding kuka with apple description for gazebo
    [apple.xacro, iiwa7_apple.xacro, iiwa7_description.xacro]
2025-09-22 corrected apple.xacro
    [apple.xacro]
2025-09-23 launch files for kuka arm with apple launch
    [iiwa7_apple.xacro]
2025-09-23 removed duplicated iiwa7 description
    [iiwa7_apple.xacro, iiwa7_description.xacro]
2025-10-14 Revise README for KUKA ARM setup and instructions
    Updated README to include additional setup instructions
2025-10-15 added moveit+gazebo support for apple plucking scenario
    [apple.xacro, iiwa7_apple.xacro]
2025-10-15 adding untracked folder
    [apple.xacro, iiwa7_apple.xacro]
2025-10-16 changes to add apple pull in gazebo scenario
    [iiwa7_apple.xacro]
2025-10-20 move arm to initial position for impedance control scenario
2025-10-22 changes to correctly pass robot_description to python file
    [apple_pluck_impedance.yaml]
2025-10-22 changing initial move mode to use joint_positions command
2025-10-22 remove incremental move for initial move or arm to start position
2025-10-22 adding velocity limit for movement
2025-10-27 fixing yaml file issue for config
    [apple_pluck_impedance.yaml]
2025-10-27 change to check the 7 joints indivisually to check if we reached start position
2025-10-30 fixing yaml file read for parameter
    [apple_pluck_impedance.yaml]
2025-10-31 logic to gracefully tear down joint-command pub and then shutdown
2025-11-03 move shutdown of node to main thread
2025-11-03 calling sys exit explicitly to terminate displacement node thread
2025-11-05 adjusting yaml for err tolerance
    [apple_pluck_impedance.yaml]
2025-11-10 removing ros_control tag from robot description urdf for optas in admittance control
2025-11-10 adding stiffness knob for motion resistance in admittance control
    [apple_pluck_impedance.yaml]
2025-11-13 changing update rate of nodes to 200 Hz
2025-11-21 adding a force bias calculator to calculate initial drift at admittance
    [apple_pluck_impedance.yaml]
2025-11-21 Revert "adding a force bias calculator to calculate initial drift at admittance"
    This reverts commit 3b24d8c1fbe351414236e9c5bc5a36eb5d38caac.
    [apple_pluck_impedance.yaml]
2025-11-24 adding force torque bias calculator to prevent admittance drift
    [apple_pluck_impedance.yaml]
2025-11-24 resolveing calibrator crash
2026-04-28 Refactor to KUKA native impedance control & tune movement tolerances
    [apple_pluck_impedance.yaml, apple_pluck_impedance_perturb.yaml]
2026-04-28 read initial poisition from interpolated joint position
2026-04-28 fix: resolve move_to_start gating and soft impedance velocity crashes
2026-04-28 fixed timer assignment issue
2026-05-06 added safety for max acceleration of the joint
2026-05-06 correcting the last apple pluck snap stage
2026-05-06 dynamically calculate the minimum safe duration needed to drop the tension
2026-05-06 handle tension release towards the end
2026-05-06 removed the previous changes to handle tension as it worsened the issue
2026-05-11 debugging timer issues for multi trial session
2026-05-11 fixing the perturb tolerance values and audio cues
    [apple_pluck_impedance.yaml, apple_pluck_impedance_perturb.yaml, virtual_fixtures_params.yaml]
2026-05-11 fixing parameters for restricted plane and adding contraint profiles
    [virtual_fixtures_params.yaml]
2026-05-11 issue with current pose unpacking from optas
2026-05-13 stricter contraint for pull axis and oscillating axis
    [virtual_fixtures_params.yaml]
2026-06-01 use clik controller to separate our hw and ros stack for better control
    [custom_hardware_controllers.yaml, custom_ros2_controllers.yaml]
2026-06-02 making the correct executable file
    [virtual_fixtures_params.yaml]
2026-06-02 moved from cartesian_impedance_controller to clik controller everywhere
    [custom_hardware_controllers.yaml, custom_ros2_controllers.yaml]
2026-06-04 cad design for end effector load
    [apple_pluck_end_effector.scad]
2026-06-08 change the move completion to cartesian completely
    [custom_hardware_controllers.yaml]
2026-06-09 separating clik controller from joint space controller for apply pluck experiments
    [custom_hardware_controllers.yaml, custom_ros2_controllers.yaml]
2026-06-10 renamed controller launch files for readbility
    [iiwa7_hardware_controllers.yaml]
2026-06-10 adding the spring release after end of trial
2026-06-10 change threshold behaviour for apple reach and add EE load determination on arm
2026-06-10 locally adding hardware sys cfg to raise torque limit
2026-06-11 end effector design and renders in scad
    [apple_ball.stl, apple_core.stl, apple_pluck_end_effector.scad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]
2026-06-12 end effector design render
    [adj_shaft.stl, apple_ball.stl, apple_core.stl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]
2026-06-12 adding delay for virtual fixture and clik controller
    [apple_pluck_impedance_perturb.yaml]
2026-06-29 fixing move in restricted plane
    [apple_pluck_end_effector.scad, base.stl]
2026-06-29 changes to get move in restricted plane using clik controller to right start pos
    [iiwa7_hardware_controllers.yaml]
2026-06-29 switching controller for move to start in restricted movement
2026-07-09 changes in ee design with corrected dimensions
    [adj_shaft.stl, apple_ball.stl, apple_cap.stl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]
2026-07-13 correcting virtual fixtures movement
    [virtual_fixtures_params.yaml]
2026-07-13 parameter fixing for sinusoid
    [virtual_fixtures_params.yaml]
2026-07-14 changes in virtual fixture and the ee design parameters
    [apple_pluck_end_effector.scad, base.stl, casing.stl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]
2026-07-14 maze movement
    [iiwa7_hardware_controllers.yaml]
2026-07-15 changes in flange plate design + maze corridor params
    [apple_pluck_end_effector.scad, flange_plate.stl]
2026-07-15 change the switch controller behaviour to wait till clik controller is loaded
2026-07-15 adding safety for virtual fixture
    [maze_params.yaml, virtual_fixtures_params.yaml]
2026-08-13 refactoring maze movement and restricted plane movement action
    [adj_shaft.stl, apple_core_base.stl]
2026-08-14 moving to torque plane from clik
    [iiwa7_hardware_controllers.yaml, torque_controllers.yaml]
2026-08-19 changing torquecontrol code to match iiwa tool
2026-08-19 added initial joint position for torque config
2026-08-19 adjusting send period in torque control server code
    [torque_controllers.yaml]
2026-08-19 fixing bug in move to frame to read params unprefixed
2026-08-21 changing torque controller params
    [torque_controllers.yaml]
2026-08-21 removed IK solver step and usejoint position directly in joint impedance controller
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2026-08-21 fixing torque parameters for the arm
    [torque_controllers.yaml]
2026-08-21 changes to stop NaN cascade failure
    [torque_controllers.yaml]
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2026-08-21 adding stiffness to torque value
2026-08-21 torque control error debug
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2026-08-24 reverting back to CLIK based controller for restricted plane and maze
    [iiwa7_hardware_controllers.yaml, torque_controllers.yaml]
2026-08-24 added kuka clik controller type in hardware
    [iiwa7_hardware_controllers.yaml]
2026-08-24 chaning the parameter values to prevent tripping of the stack in arm
    [maze_params.yaml, virtual_fixtures_params.yaml]
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2026-09-08 end effector circuitry code for setup and neopixels
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2026-09-13 reverting ee roll changes
    [apple_pluck_impedance.yaml, apple_pluck_impedance_perturb.yaml, maze_params.yaml]
2026-09-13 apple pluck expt start position reverted
    [apple_pluck_impedance.yaml, apple_pluck_impedance_perturb.yaml]
2026-09-21 changes in end effector design
    [adj_shaft.stl, apple_ball.stl, apple_cap.stl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]
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2026-09-23 changes in data recording and end effector design
    [apple_pluck_end_effector.scad, casing.stl, cover.stl]
2026-09-24 adding control gui
    [iiwa7_hardware_controllers.yaml]
2026-09-25 changes in logging development history in readme
    [apple_pluck_end_effector.scad, iiwa7_hardware_controllers.yaml]
2026-09-30 moved velocity and position to live run parameter
2026-09-30 adding more tunable parameter in arm for maze
2026-10-01 change in controller switch for pre training task
2026-10-07 changing apple stem to make it moreflexible
    [apple_pluck_end_effector.scad, apple_stem.stl]
2026-10-13 adding resistance change slider during apple pluck and perturn experiment
2026-10-14 added slider to change the speed of move of arm
2026-10-20 improving maze movement resistance by changing clik dt

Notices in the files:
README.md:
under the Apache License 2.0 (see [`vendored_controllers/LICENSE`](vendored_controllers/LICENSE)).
